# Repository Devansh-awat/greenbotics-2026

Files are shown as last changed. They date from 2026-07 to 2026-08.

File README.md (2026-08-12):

|  |
| :----------------------------------------------------------: |

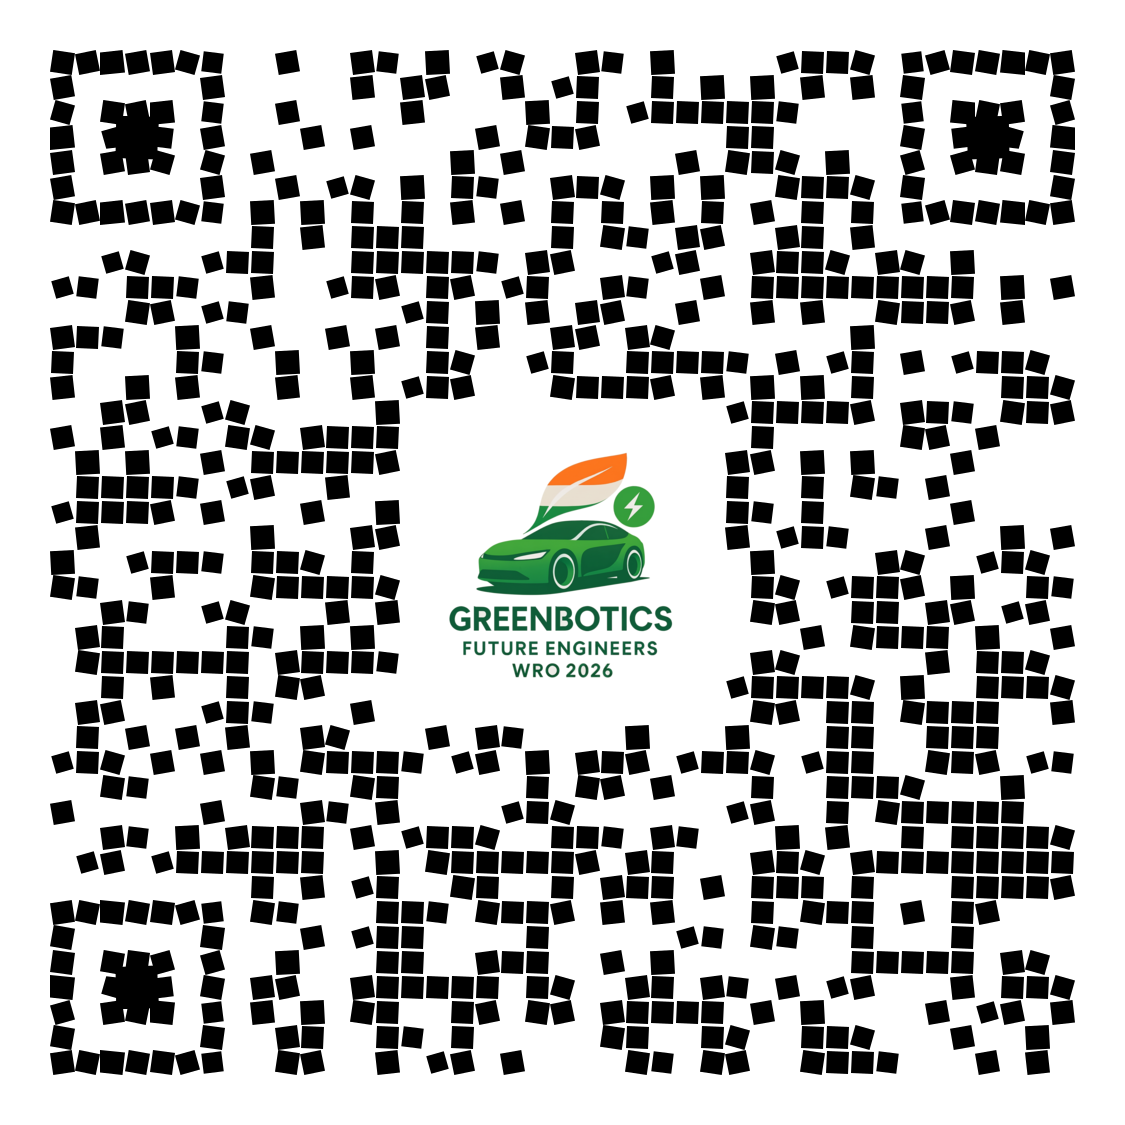
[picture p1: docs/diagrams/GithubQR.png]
GithubQR
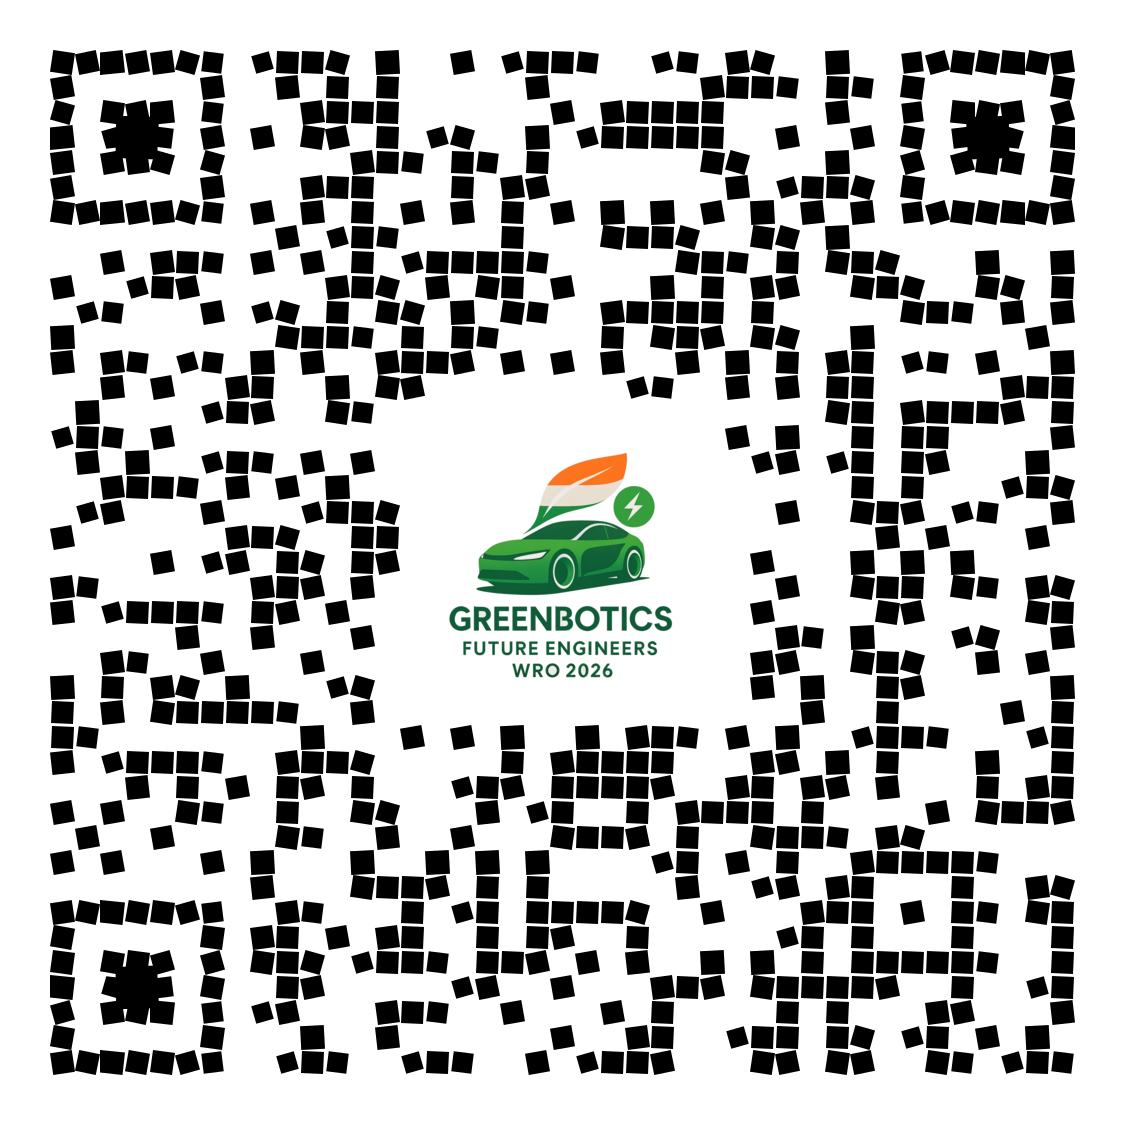
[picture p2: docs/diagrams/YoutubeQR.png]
YoutubeQR
|  |  |
| :--- | ---: |
| Scan QR to open Github repo | Scan QR to open YouTube video |

# Table of Contents

1. [Introduction](#1-introduction)
   - 1.1 [Summary and Performance Video](#11-summary-and-performance-video)
   - 1.2 [Vision](#12-vision)
   - 1.3 [The Team](#13-the-team)
   - 1.4 [Vehicle photos](#14-vehicle-photos)
2. [Mobility & Mechanical Design](#2-mobility--mechanical-design)
   - 2.1 [Drivetrain selection](#21-drivetrain-selection)
   - 2.2 [Steering selection](#22-steering-selection)
   - 2.3 [Vehicle dimensions](#23-vehicle-dimensions)
   - 2.4 [Differential assembly selection](#24-differential-assembly-selection)
   - 2.5 [Wheel selection](#25-wheel-selection)
   - 2.6 [Speed Torque Calculation (Drive Motor Selection)](#26-speed-torque-calculation-drive-motor-selection)
   - 2.7 [Steering Motor selection](#27-steering-motor-selection)
   - 2.8 [3D printed parts](#28-3d-printed-parts)
   - 2.9 [Experiments](#29-experiments)
3. [Power & Sensor Architecture](#3-power--sensor-architecture)
   - 3.1 [Power Budget](#31-power-budget)
   - 3.2 [Power Strategy](#32-power-strategy)
   - 3.3 [Power Verification](#33-power-verification)
   - 3.4 [Wiring Diagram and PCB](#34-wiring-diagram-and-pcb)
   - 3.5 [Sensors](#35-sensors)
   - 3.6 [Microcontroller — Raspberry Pi 5 as Single Controller](#36-microcontroller--raspberry-pi-5-as-single-controller)
   - 3.7 [Calibration Procedures](#37-calibration-procedures)
   - 3.8 [Failure Point Analysis](#38-failure-point-analysis)
   - 3.9 [Iteration Evidence](#39-iteration-evidence)
4. [Software Architecture & Obstacle Strategy](#4-software-architecture--obstacle-strategy)
   - 4.1 [Design Philosophy](#41-design-philosophy)
   - 4.2 [System Architecture](#42-system-architecture)
   - 4.3 [Open Challenge Flow Chart and Algorithm](#43-open-challenge-flow-chart-and-algorithm)
   - 4.4 [Obstacle Challenge — State Machine & Algorithms](#44-obstacle-challenge--state-machine--algorithms)
   - 4.5 [Edge Cases](#45-edge-cases)
   - 4.6 [Parameter Tuning](#46-parameter-tuning)
   - 4.7 [RPM Control — PI Controller with Feed-Forward](#47-rpm-control--pi-controller-with-feed-forward)
   - 4.8 [Testing Results](#48-testing-results)
   - 4.9 [Performance Optimizations](#49-performance-optimizations)
   - 4.10 [Troubleshooting and Debugging](#410-troubleshooting-and-debugging)
5. [Systems Thinking & Engineering Decisions](#5-systems-thinking--engineering-decisions)
   - 5.1 [System Overview](#51-system-overview)
   - 5.2 [Shared Constraints](#52-shared-constraints)
   - 5.3 [Cross-Subsystem Decision Case Studies](#53-cross-subsystem-decision-case-studies)
   - 5.4 [Risk & Failure Modes](#54-risk--failure-modes)
   - 5.5 [Iteration and Testing Cycle Summary](#55-iteration-and-testing-cycle-summary)
6. [Reproducibility & GitHub Organization](#6-reproducibility--github-organization)
   - 6.1 [Repository Structure & Module Map](#61-repository-structure--module-map)
   - 6.2 [Robot Build Instructions](#62-robot-build-instructions)
   - 6.3 [Software Setup & Running the Robot](#63-software-setup--running-the-robot)
   - 6.4 [Testing Workflow](#64-testing-workflow)   
   - 6.5 [Parts List (Bill of Materials)](#65-parts-list-bill-of-materials)
   - 6.6 [Engineering Journal](#66-engineering-journal)
   - 6.7 [Matlab Journal](#67-matlab-journal)

---

# 1 Introduction 
We are team Greenbotics and are competing in WRO 2026 Future Engineers category. This is our second year after a successful participation in WRO 2025, where we were one of the 5 teams to hit a full score(https://scoring.wro-association.org/en/event/scoring/293) in all 4 rounds. You can find our documentation from 2025 here (https://github.com/Devansh-awat/greenbotics).



## 1.1 Summary and Performance Video
Here is a quick 5 min video that summarizes the essence of our robot and documentation. We recommend you watch it to get a quick understanding of our project!

| [Robot Video](https://m.youtube.com/playlist?list=PLMdippUF4xxo) | [YoutubeQR](https://m.youtube.com/playlist?list=PLMdippUF4xxo) <br />Scan QR code to open in YouTube |
| --- | --- |

* [Summary Video](https://youtu.be/YS-oyNQQUGs) 
* [Open Challenge Performance Video](https://youtu.be/OW5V_LRIKNU)
* [Obstacle Challenge Performance Video](https://youtu.be/RbtGV2t9GcI)

## 1.2 Vision
Even though we had a robot from WRO 2025 that performed perfectly across all rounds, we decided to make the most of the 6 months we had to prepare for WRO 2026 by redesigning our robot in every aspect and building it from scratch. This experience gave us tremendous learning.

## 1.3 The Team

<table style="width: 100%; text-align: center; border-collapse: collapse;">
   <tr>
    <td style="padding: 10px;">
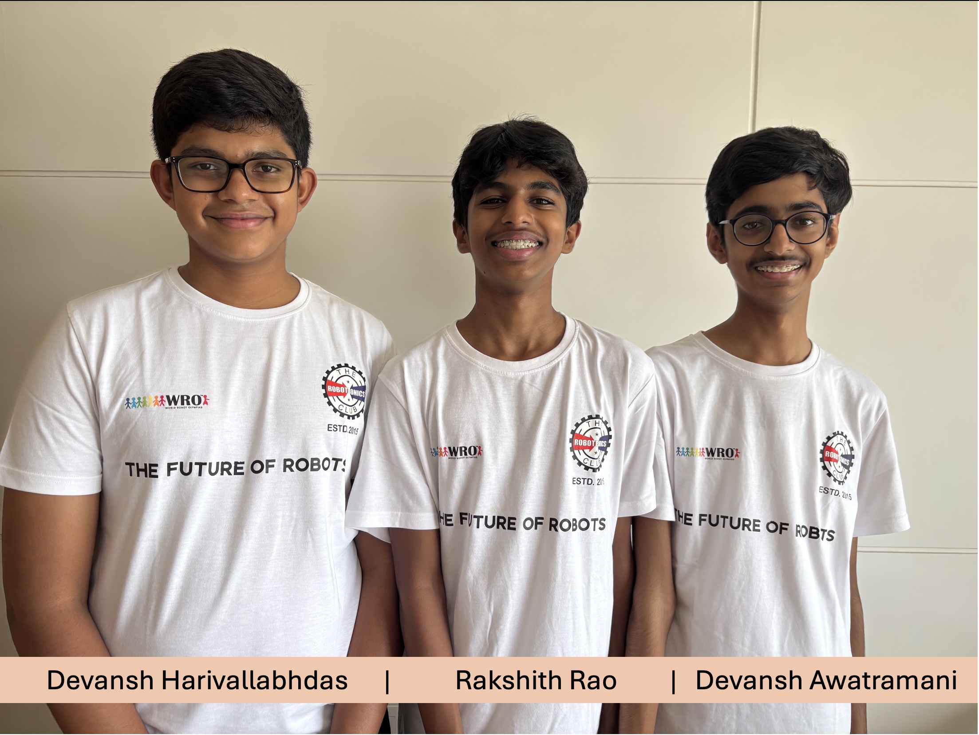
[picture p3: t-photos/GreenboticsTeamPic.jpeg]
      
    </td>
    <td style="padding: 10px;">
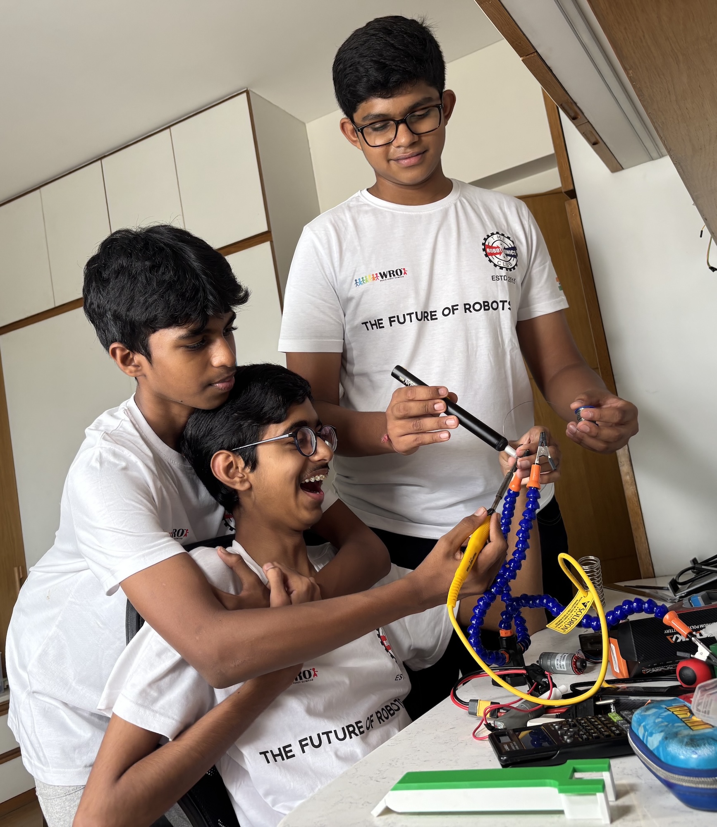
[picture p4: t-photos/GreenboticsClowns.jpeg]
     
    </td>
  </tr>
</table>

Devansh Awatramani and Rakshith Rao are Grade 10 students at The Riverside School, Ahmedabad. Devansh Harivallabhdas is a Grade 11 student at Ahmedabad International School, Ahmedabad.

Paresh Gambhava is our coach from The Robotronics Club, Ahmedabad

## 1.4 Vehicle photos

<table>
  <tr>
    <td align="center">
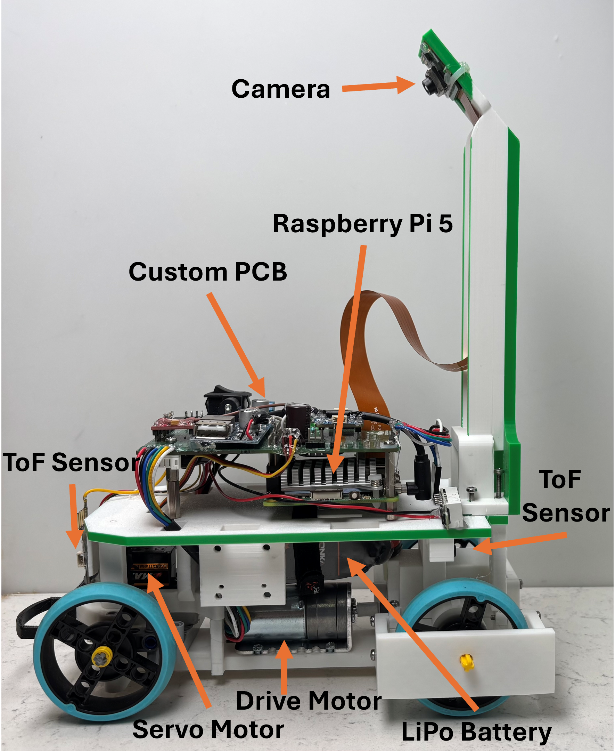
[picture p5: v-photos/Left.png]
Left View
      <br>
      <b>Left</b>
    </td>
       <td align="center">
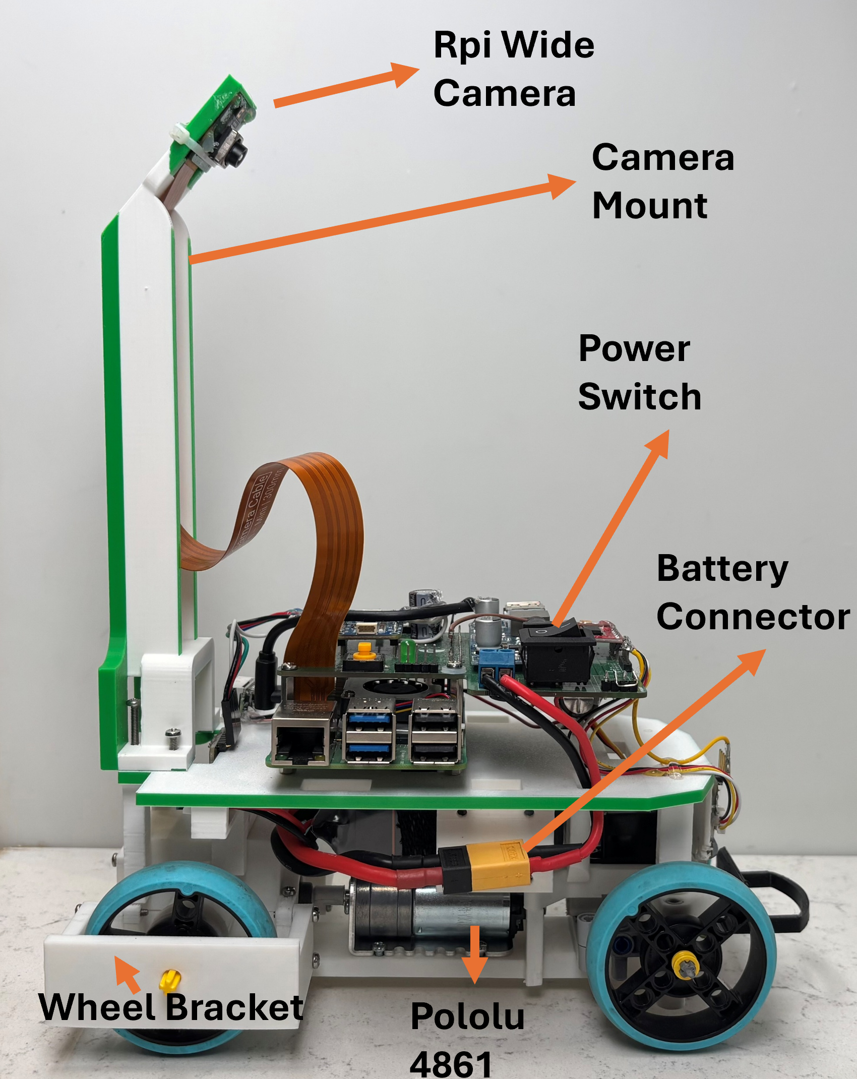
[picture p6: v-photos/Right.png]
Right View
      <br>
      <b>Right</b>
    </td> 
    <td align="center">
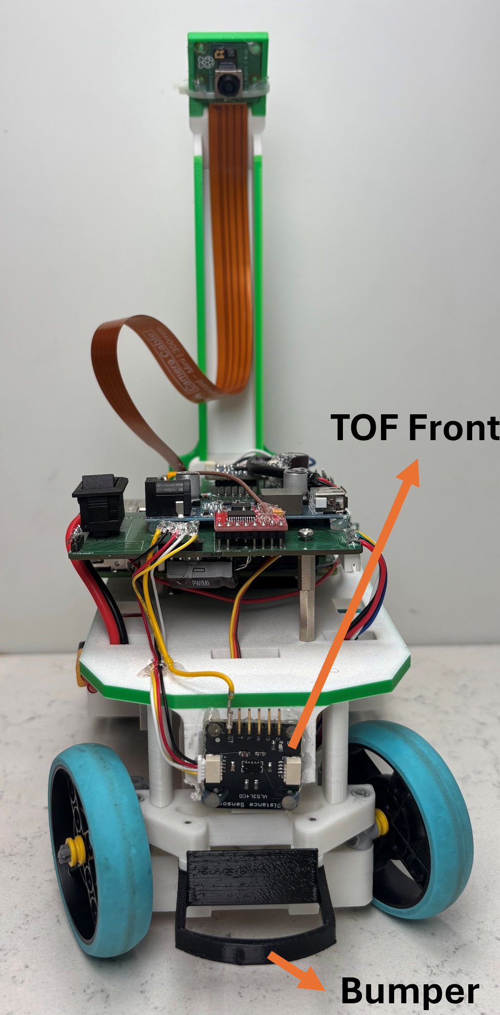
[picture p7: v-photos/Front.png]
Front View
      <br>
      <b>Front</b>
    </td>
    <td align="center">
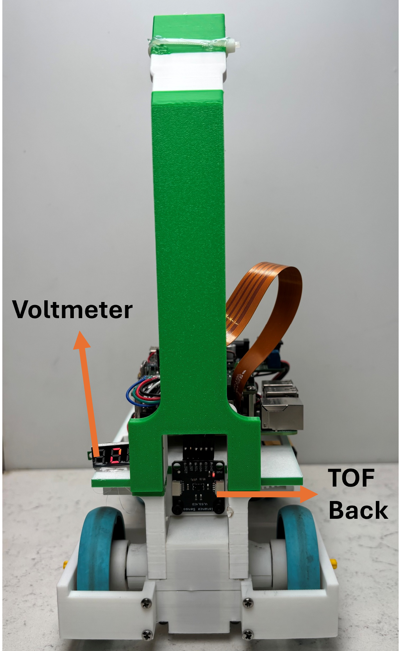
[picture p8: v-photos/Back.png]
Back View
      <br>
      <b>Back</b>
    </td>
   </tr>
</table>

<table>
  <tr>
   <td align="center">
      Top View<br>
      <b>Top</b>
    </td>
    <td align="center">
      Bottom View<br>
      <b>Bottom</b>
    </td> 
  </tr>
</table>

# 2 Mobility & Mechanical Design

This section describes the Mecahnical design of the robot including its chassis, drivetrain and gearbox. It also mentions our experiments, speed & torque calculations, component selection criteria , 3-D designed parts and vehicle photos.

---

## 2.1 Drivetrain selection

WRO rules do not allow a differential drive robot. This steers us towards a real vehicle like design that consists of a front wheel steering. These vehicles have multiple drive options

|  | All Wheel Drive | Front Wheel Drive | Rear Wheel Drive |
| :---- | :---- | :---- | :---- |
|  Driving power | All wheels | Front wheels | Rear wheels |
| Physical complexity | Transfer rotational force to a wheel that is changing its angles with respect to chassis | Transfer rotational force to a wheel that is changing its angles with respect to chassis | Simpler design. Rear axis \- rotational force. Front axis \- turning force |
| Mechanical complexity | Drive motor mounted on steering mechanism. Requires powerful servo due to extra weight | Drive motor mounted on steering mechanism. Requires powerful servo due to extra weight | **Separates mechanical responsibilities.** Steering and Drive motors mounted on separate axis |
| Highlights | Off roading, steep inclines, muddy road | Pulling over obstacles  | Smooth roads, better turns |

We chose RWD for its simpler design and smoother turns.   

<table>
  <thead>
    <tr>
      <th>Differential Gear</th>
      <th>Diagram</th>
    </tr>
  </thead>
  <tbody>
    <tr>
      <td>The rear wheels have a differential gear to prevent inner wheels from skidding when turning. As shown in the diagram, during turns, the outer wheel covers more distance(wo) than inner wheels (wi). In absence of differential gear, the inner wheels would skid.
      </td>
      <td >
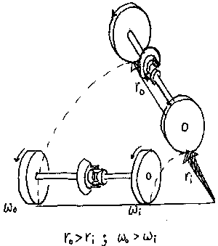
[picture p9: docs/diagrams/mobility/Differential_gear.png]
Differential Gear
       
      </td>
    </tr>
  </tbody>
 </table>   

---

## 2.2 Steering selection

**Ackermann vs Parallel**  
We used Parallel steering in our last year's robot. We realised certain manoeuvres such as entering parking space and tight turns between two inner blocks and inner walls caused tyre slip. We improved upon this aspect for this year's robot by using Ackermann steering. In Ackerman steering, the inner wheel turns slightly more than the outer wheel, so the robot stays on the same arc without tyre slip. This improves maneuverability especially during cornering.

| Ackermann Steering Concept |Our Robot Design | Our Steering Geometry for Ackermann Steering |
| :---: | :---: | :---: |
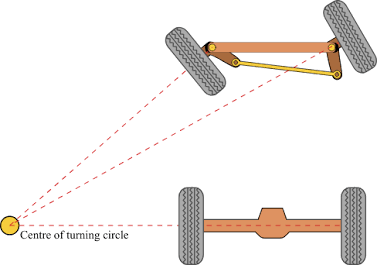
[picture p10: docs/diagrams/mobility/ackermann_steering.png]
Ackermann Steering
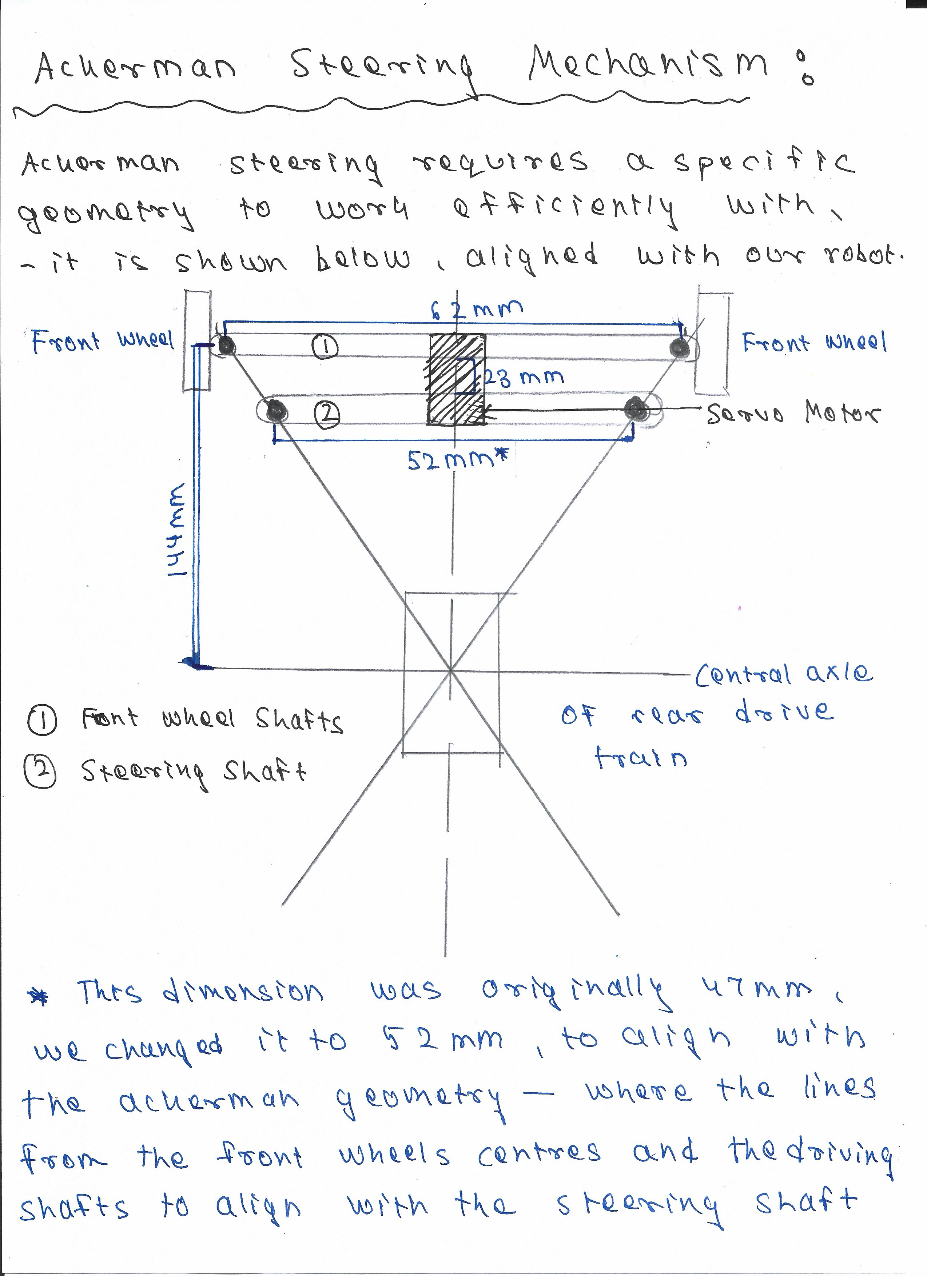
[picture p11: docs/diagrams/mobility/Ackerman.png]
Ackermann Reference Robot Geometry
|  | Ackermann Reference Robot |  |

---

## 2.3 Vehicle dimensions

The defining constraint in this vehicle is its turning radius for its parallel parking. The turning radius is defined by the dimensions of the vehicle.

<table>
  <thead>
    <tr>
      <th>Length Impact & Formula</th>
      <th>Length Visual</th>
      <th>Width Impact & Formula</th>
      <th>Width Visual</th>
    </tr>
  </thead>
  <tbody>
    <tr>
      <td>
        <strong>Length Impact</strong><br>
        <em>R = L / sin(θ)</em><br>
        Turning Radius(R) scales proportionally with the Length(L) of the vehicle.
      </td>
      <td>
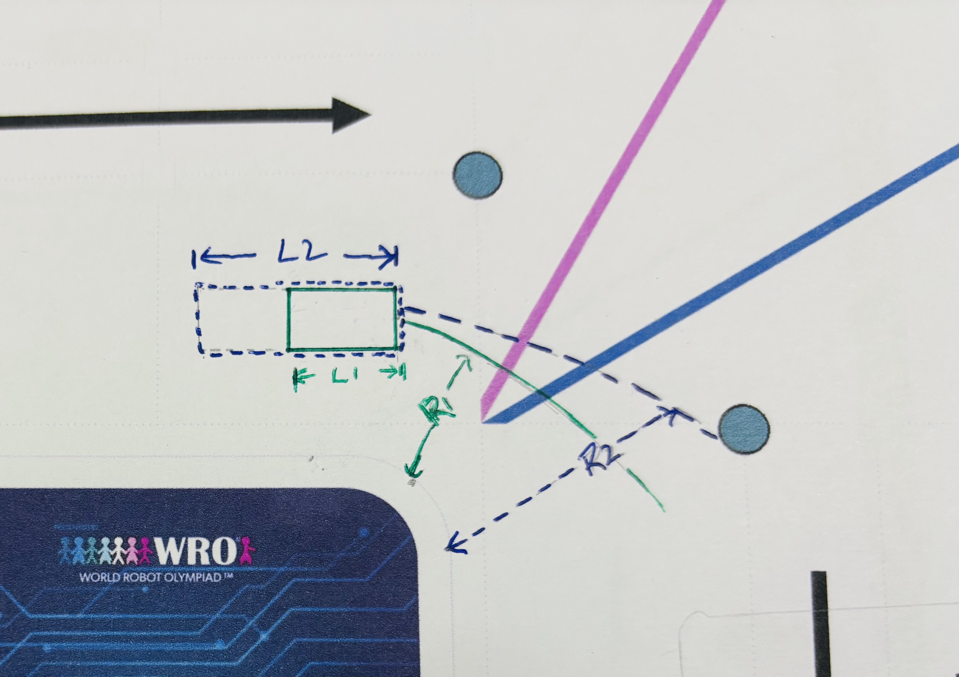
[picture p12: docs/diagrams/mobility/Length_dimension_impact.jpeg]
Vehicle Length Impact Diagram
        
      </td>
      <td>
        <strong>Width Impact</strong><br>
        <em>R(outer) = R(center) + W/2</em><br>
        Width does not change the turning radius, but increases the outer clearance radius.
      </td>
      <td>
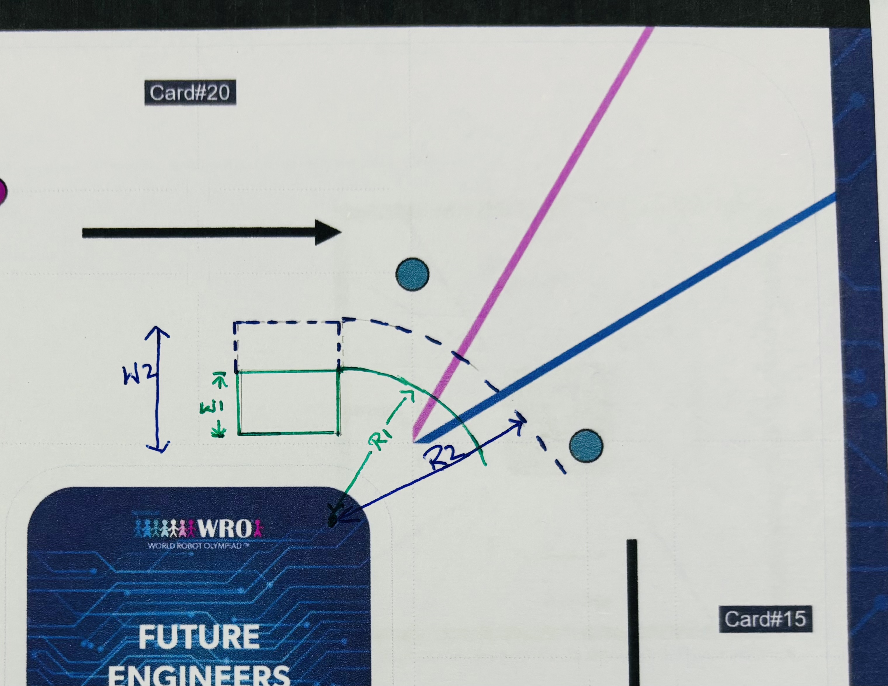
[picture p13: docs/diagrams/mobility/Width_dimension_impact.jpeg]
Vehicle Width Clearance Diagram
        
      </td>
    </tr>
  </tbody>
</table>

We strive to keep both the Length and Width as minimum as possible.  
Length is the minimum length to accommodate the differential gear assembly, drive motor and the steering assembly back to back.  
Width is the minimum width for the differential assembly, couplings and the wheels attached back to back.  
This results into a 23 cm long and 12 cm wide vehicle.

---

## 2.4 Differential assembly selection

We used Lego differential gear assembly in our last year's robot. While this gave us adequate performance, there were few drawbacks to it

1) Gear damage: Plastic gears chip away after continued use..  
2) Backlash: When the robot makes micro adjustments during parking switching from forward to reverse, the motor rotates slightly before the wheels actually move. This makes software control of the robot inconsistent. If we move the motor a bit more, the robot sometimes hits the walls, if we make the motor move a bit less, it doesn't move.

Both these problems can be resolved with metal differential gears. To allow for precise control, we chose the largest possible gear ratio that could fit in the chassis. We chose a metal differential gear with a 38:13 ratio of ring gear to pinion gear. This gear ratio gives higher torque providing reliable transmission even at lower speeds. There is loss of top speed, but we do not need to race the car so that is fine.

| Feature | Plastic Differential (e.g., LEGO) | Metal Differential |
| :---- | :---- | :---- |
| **Backlash**  | High (Rough control at low speed during parking) | Low (Precise control at low speed during parking) |
| **Friction** | Plastic-plastic \- higher friction (Prone to low-speed jerky motion) | Metal-metal \- lower friction (Smooth low-speed crawl) |
| **Rigidity / Prone to damage** | Teeth Chip away after continued usage | Rigid and stable |
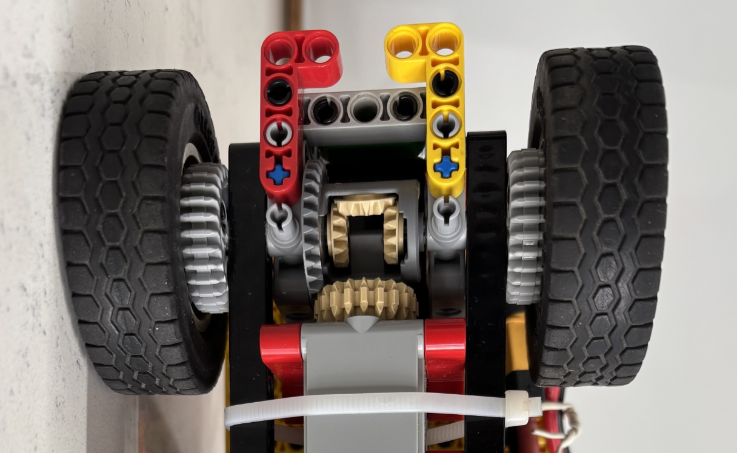
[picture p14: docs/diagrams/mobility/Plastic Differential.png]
Metal Plastic Differential gear
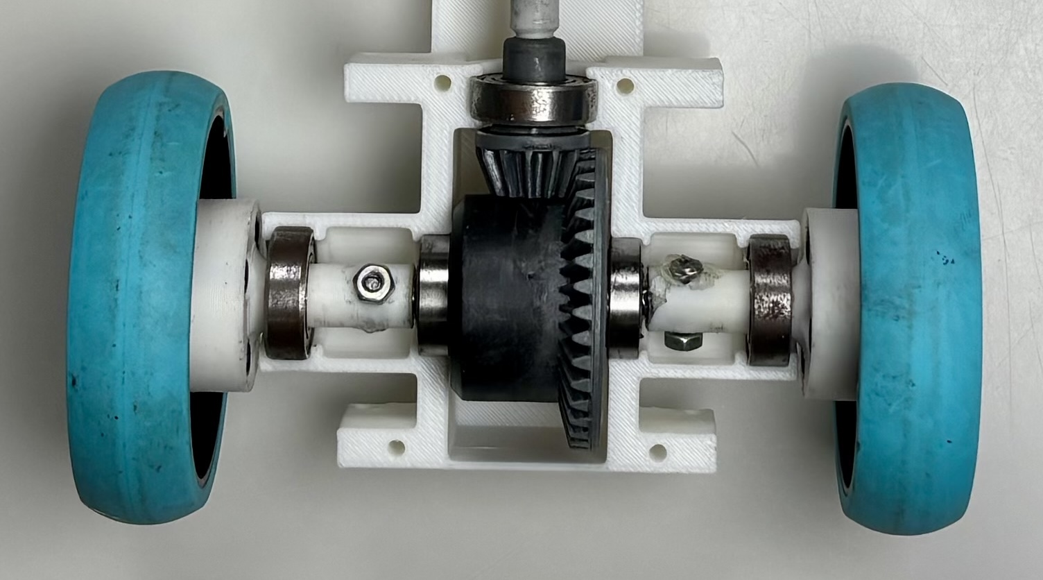
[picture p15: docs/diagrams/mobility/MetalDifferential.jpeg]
Metal Plastic Differential gear
| **Robot Image with Gear** |||

---

## 2.5 Wheel selection

We used lego spike prime medium wheels with 56mm diameter and 14 mm wide. These are narrow bicycle like wheels giving smoother turns. A bigger wheel would amplify the backlash causing imprecise movements during parking.

We also tried 3D printing our own custom wheels, and coating it with a cricket bat's rubber grip. But we realised we couldn't match the fit and finish of a pre-fabricated Lego wheel.

[For Wheel Attempts refer Section 5.5.1 3D Iterations](#551-3d-chassis-iterations)

---

## 2.6 Speed Torque Calculation (Drive Motor Selection) 

We used a Lego EV3 medium motor in our last year's robot and its speed was the limiting factor for our robot. We were running the motor at 100% speed and couldn't go faster.   
Old robot rpm at wheel

```
rpm_wheel_old = rpm_motor_old / differential_gear_ratio_old

rpm_wheel_old = 250 / (28 / 20) = 250 / 1.4 = 179
```

We wanted the new robot to go at least 50% faster with enough headroom so we aimed for 100% higher rpm at wheel

```
rpm_wheel_new = rpm_motor_new / differential_gear_ratio_new

rpm_wheel_new = 2 * rpm_wheel_old = 2 * 179 = 358

358 = rpm_motor_new / (38 / 13)
rpm_motor_new = 358 * (38 / 13) = 358 * 2.92 = 1045
```

We explored different motors from [Pololu](https://www.pololu.com/product/4861) as they offer a wide range of gear ratios. We ran below Speed Torque calculations with some motors and shortlisted Pololu 4861 that provides 0.71 kg·cm torque @ 1800 rpm. This motor runs at 12V removing the need for a step down converter and associated efficiency losses.

| Criteria | LEGO EV3 Medium Motor | Pololu 4861 |
| :---- | :---- | :---- |
| Power supply match | Needs buck converter (12 V → 9V), small conversion loss | Runs directly off 12 V LiPo, no converter required |
| Mechanical reliability | Plastic gears —  can slip or chip away and has higher backlash | All-metal gearbox — More reliable and has lower backlash |
| No load speed | 250 rpm | 1800 rpm |
| Stall torque | 1.22 kg·cm | 0.71 kg·cm |
| Rated stall current | 0.8 A | 1.8 A |

The Pololu motor natively matches the power source and has better mechanical reliability.

### 2.6.1 Speed Torque calculations

| Symbol | Meaning | Value |
| :---- | :---- | :---- |
| m | Robot mass | 0.8 kg |
| g | Gravitational acceleration | 9.81 m/s² |
| W | Robot weight \= m × g | 7.85 N |
| D\_w , r\_w | Wheel diameter / radius | 0.056 m / 0.028 m |
| N\_nl | Motor no-load speed at gearbox output (12 V) | 1800 RPM |
| T\_stall\_gb | Stall torque at gearbox output (extrapolated) | 0.71 kg·cm \= 0.0696 N·m |
| I\_stall | Stall current | 1.8 A |
| G\_ext | External gear ratio (13:38 metal differential) | 38 / 13 \= 2.923 |
| μ | Wheel-to-mat friction coefficient (assumed) | 0.6 (rubber-type wheel on flex banner) |
| C\_rr | Rolling resistance coefficient (assumed) | 0.03 |
| C\_rr,static | Higher than C\_rr due to stiction | 0.05 |
| T\_cont\_gb | Recommended continuous torque at gearbox output | 25% of T\_stall\_gb (manufacturer guideline: keep current ≤ 25% of stall) |

**No load speed**

```
v_nl = (π × D_w × N_nl) / (60 × G_ext)

v_nl = (π × 0.056 × 1800) / (60 × 2.923) = 1.81 m/s
```

**A) Starting Torque v/s Stall Torque rating**

Can the motor move the robot from a dead stop? The motor is in stall condition at the moment it starts and the stall torque should exceed the initial resistance(static friction) that the robot needs to begin moving.

**B) Running Torque v/s Continuous Torque rating**

Is the torque required for continuous driving comfortably within motor's output to avoid constantly overloading the motor that could result in motor breakdown

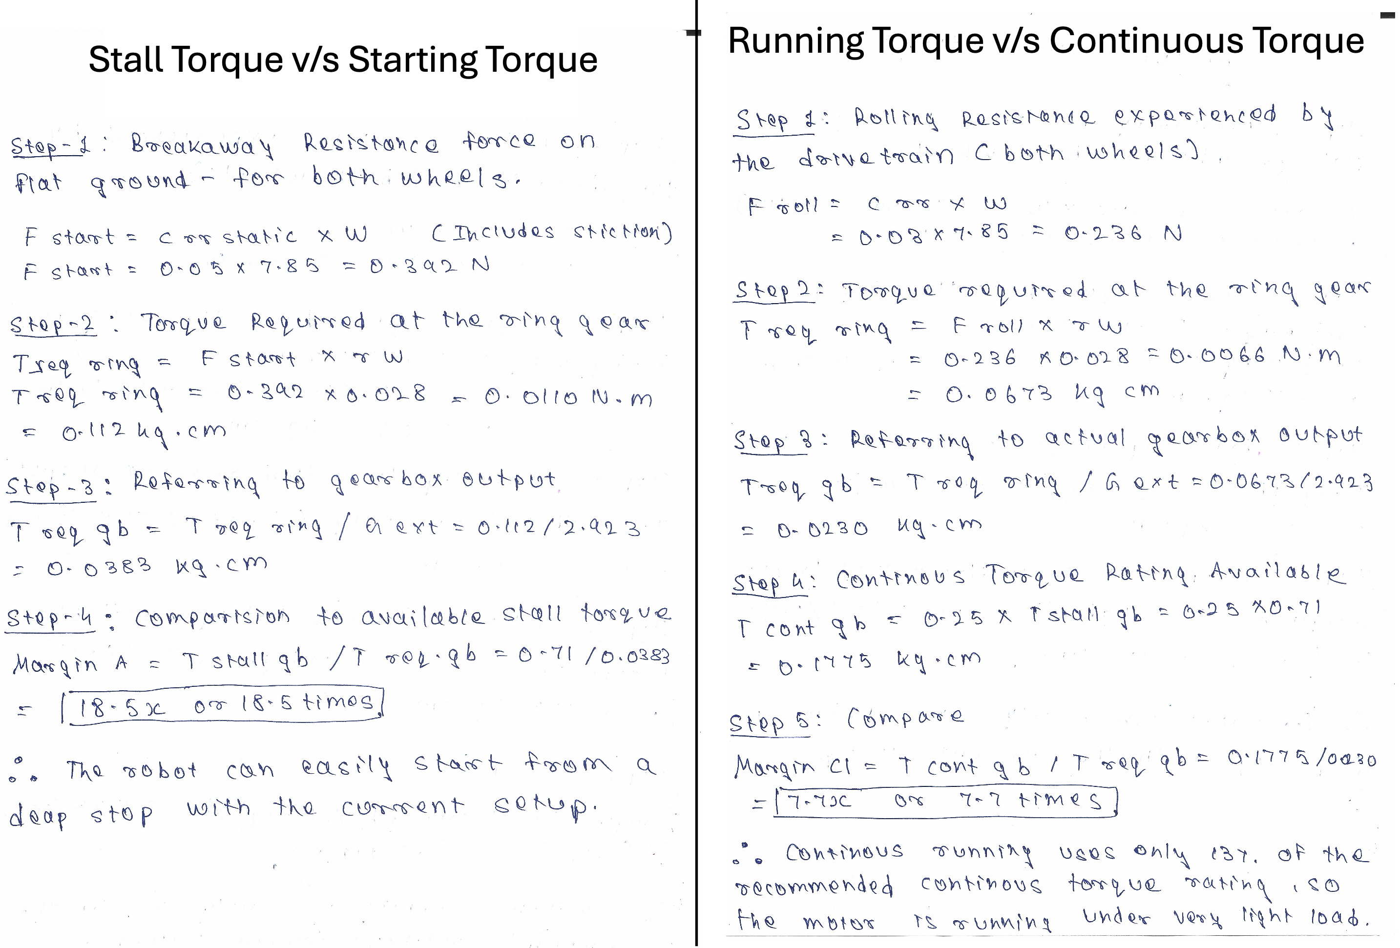
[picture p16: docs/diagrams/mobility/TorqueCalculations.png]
Starting Torque Calculation


**C) Running speed v/s No load speed**

The Pololu 4861 datasheet ([https://www.pololu.com/file/0J1829/pololu-25d-metal-gearmotors-rev-2-0.pdf](https://www.pololu.com/file/0J1829/pololu-25d-metal-gearmotors-rev-2-0.pdf)) shows that torque and speed are linearly related. 

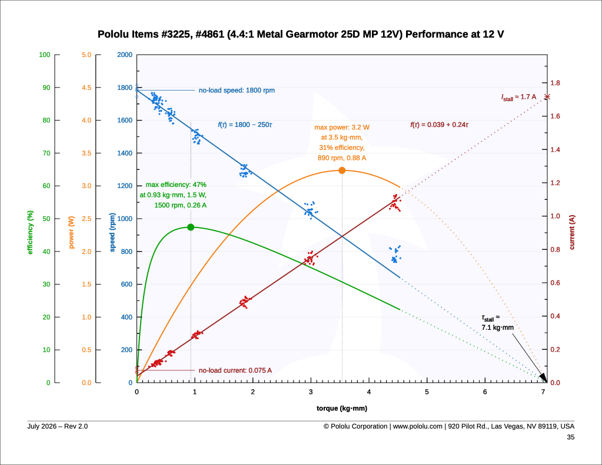
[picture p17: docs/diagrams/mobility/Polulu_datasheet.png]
Pololu Datasheet


Using the fraction of stall torque with the running torque from (b) 

```
N_gb = N_nl × (1 − T_req,gb / T_stall_gb)

N_gb = 1800 × (1 − 0.0230/0.71) = 1800 × 0.9676 = 1741.7 RPM

N_wheel = N_gb / G_ext = 1741.7 / 2.923 = 595.8 RPM

v = π × D_w × N_wheel / 60 = π × 0.056 × 595.8 / 60 = 1.75 m/s
```

*Conclusion:* The running speed (1.75 m/s) should be very close to the no load speed (1.81 m/s).

**Experiment Metrics**
|Theortical No Load Speed| Theoritical Running Speed |Observed Running Speed|
|---|---|--|
|1.81 m/s|1.75 m/s|1.54 m/s|

**Assumptions**

Our calculations assumed no loss at differential gear. However a differential gear would have efficiency of **η=85%** due to frictional losses. But, its impact wouldn't be of concern to us as we have a very high margin.

**Summary**

| Check | Question answered | Torque req'd at gearbox (kg·cm) | Torque available (kg·cm) | Margin |
| :---- | :---- | :---- | :---- | :---- |
| A: Starting Torque v/s Stall Torque rating | Can it start moving from rest? | 0.0383 | 0.71 (stall) | 18.5× |
| B: Running Torque v/s Continuous Torque rating | Can it sustain cruising without overheating? | 0.0230 | 0.1775 (25% cont.) | 7.7× |

The Pololu motor has adequate torque margin to start the robot from rest, sustain cruising without overheating and to provide the max speed we could possibly use.

---

## 2.7 Steering Motor selection

For our last year's robot, we used an SG90 servo motor for front wheel steering for precise steering control. While it was adequate, we explored other alternatives.

| SG90 | EMAX ES08A II |
| :---- | :---- |
| Softer Plastic gears prone to wear and stripping | Higher Grade Plastic and Robust Motor |
| deadband drift \- steering drifts over time | tighter deadband \- precise steering positioning |
| speed \- 0.10 sec/60° | speed \- 0.10 sec/60° |
| torque \- 1.6 kgf·cm | torque \- 2.0 kgf·cm |

We did have one instance of SG90 breaking last year so we chose the EMAX servo motor primarily for higher durability and secondarily for similar or better steering precision.

---

## 2.8 3D printed parts
Our robot structure is entirely 3-D designed. Here is how the various 3-D parts connect together to give structure to our robot. 
[Click Here to see how we iterated to reach these final parts](#551-3d-chassis-iterations)

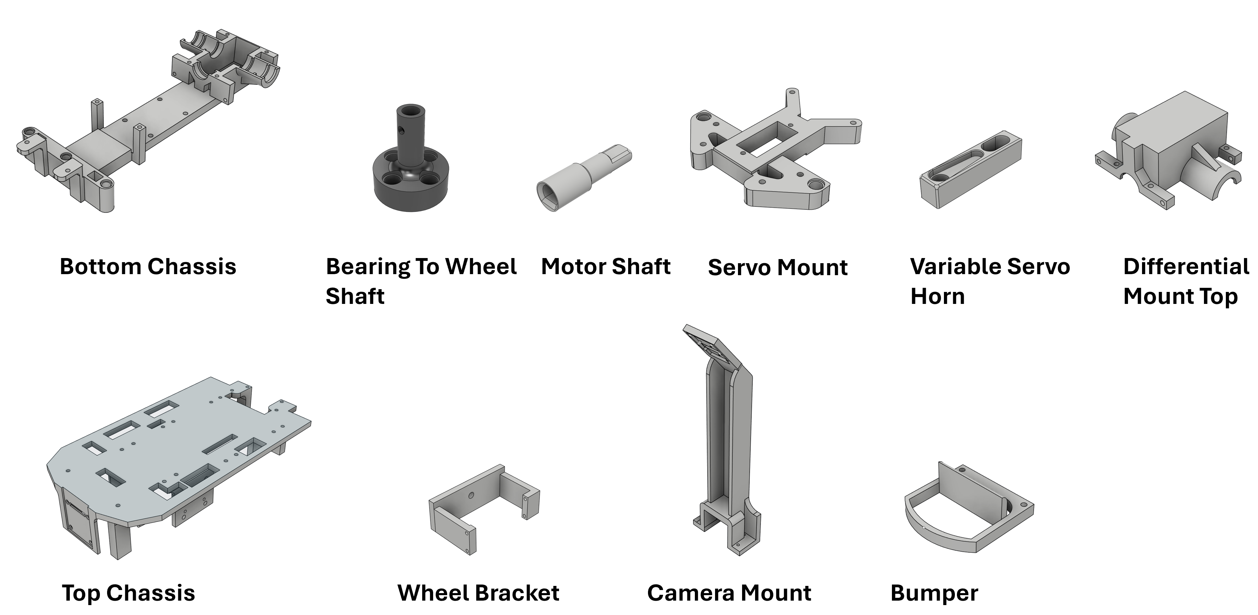
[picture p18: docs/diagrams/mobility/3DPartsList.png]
3 D parts
  

**[Link for all 3-D modelled parts photos ](schemes/)**

**[Link for all 3-D parts  STL files](models/chassis/)**

---

## 2.9 Experiments

We ran some experiments to determine our robot precision. This data helps us calibrate robot speed for various scenarios like open challenge, obstacle challenge and parking section.

### 2.9.1 Detection distance v/s speed

We ran the robot in a straight line until it found an obstacle 20 cm in front of it. The robot started breaking at the point the sensor triggered. This measures the time taken by the robot to come to a complete halt. This helps us determine how slowly the robot should move at critical points e.g. parking section.

<table>
  <tr>
    <!-- Left Column: Data Table -->
    <td valign="top">
      <table border="1" cellpadding="5" cellspacing="0">
        <thead>
          <tr>
            <th>Speed (m/s)</th>
            <th>Stopping Time (ms)</th>
            <th>Stopping Distance (cm)</th>
          </tr>
        </thead>
        <tbody>
          <tr><td align="center">0.199</td><td align="center">111</td><td align="center">0.51</td></tr>
          <tr><td align="center">0.265</td><td align="center">237.5</td><td align="center">1.65</td></tr>
          <tr><td align="center">0.334</td><td align="center">266.6</td><td align="center">2.57</td></tr>
          <tr><td align="center">0.396</td><td align="center">256.2</td><td align="center">2.76</td></tr>
          <tr><td align="center">0.456</td><td align="center">301</td><td align="center">3.59</td></tr>
          <tr><td align="center">0.523</td><td align="center">335</td><td align="center">4.6</td></tr>
          <tr><td align="center">0.588</td><td align="center">370</td><td align="center">5.8</td></tr>
          <tr><td align="center">0.653</td><td align="center">410</td><td align="center">7.1</td></tr>
          <tr><td align="center">0.719</td><td align="center">450</td><td align="center">8.6</td></tr>
          <tr><td align="center">0.784</td><td align="center">490</td><td align="center">10.2</td></tr>
        </tbody>
      </table>
    </td>
    <!-- Right Column: Chart Image -->
    <td valign="top" style="padding-left: 20px;">
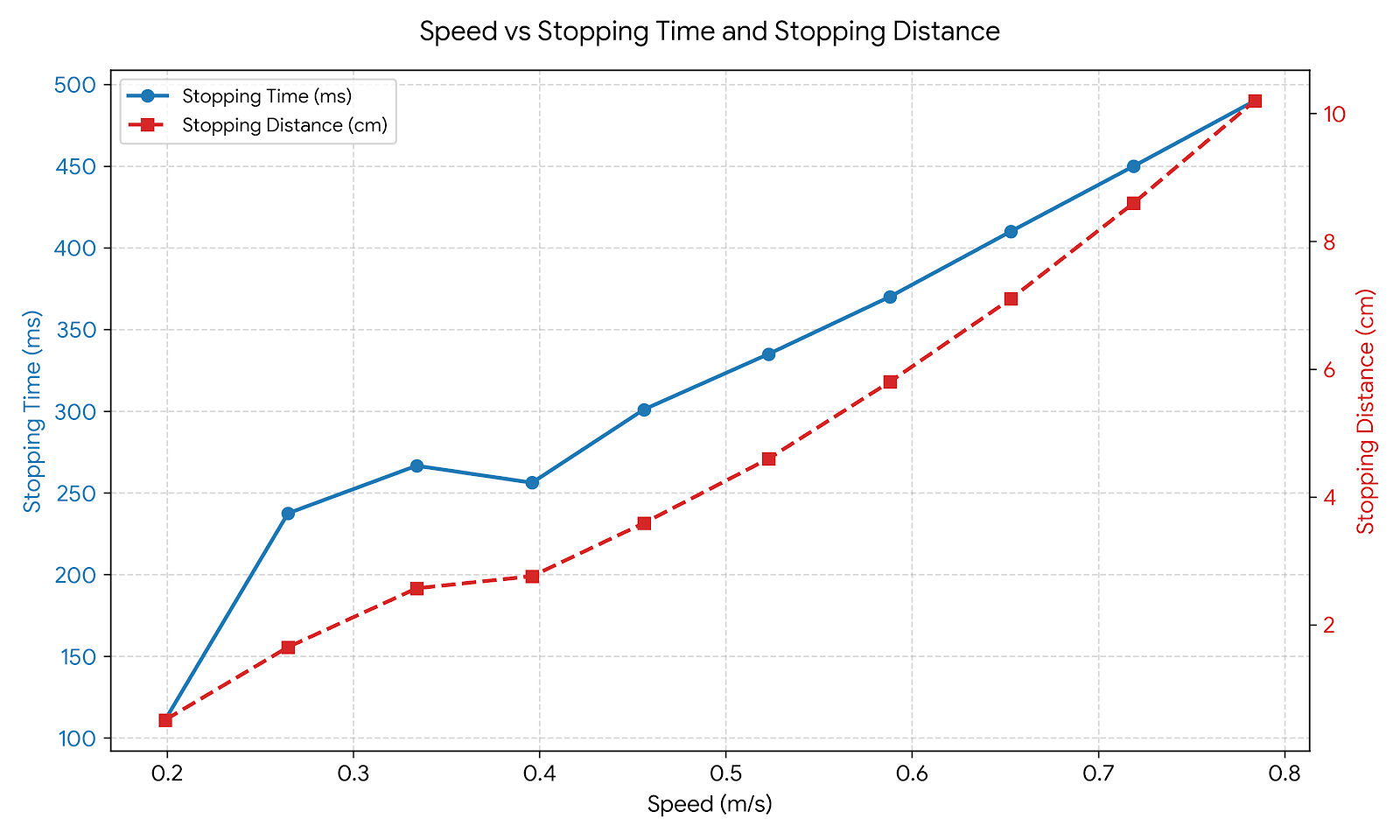
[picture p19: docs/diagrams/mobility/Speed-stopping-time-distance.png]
Speed vs Stopping Time and Distance Chart
      
    </td>
  </tr>
</table>

**Conclusion** This experiment proves that at higher speed the time taken to come to a full stop as well as distance covered before it actually stop increases, so we need to ensure robot is moving at the right speed for it to stop and turn accurately in parking or while avoiding obstacles.

### 2.9.2 Encoder precision and tuning

We used the encoder specifications and gear ratio to tune the encoder. Then we measured the actual distance travelled when it was given a particular instruction to verify its accuracy.

| Run # | Encoder measured distance (cm) | Observed distance practically (cm) | Δ distance (cm) |
| :---: | :---: | :---: | :---: |
| 1 | 100 | 92 | 8 |
| 2 | 50 | 47 | 3 |

**Conclusion** We designed our software to be able to handle the accuracy that the actual encoder can provide. 

---

# 3 Power & Sensor Architecture

A 11.1V 1500mAh 16.65 Wh LiPo battery powers all the electronics on our robot. It drives a 25W power converter providing 5.2V to the Raspberry Pi 5 and the Servo motor, while the battery directly provides 11.1V to the Drive motor. The RPi 5 further powers the camera and sensors via its 3.3V GPIO rail.

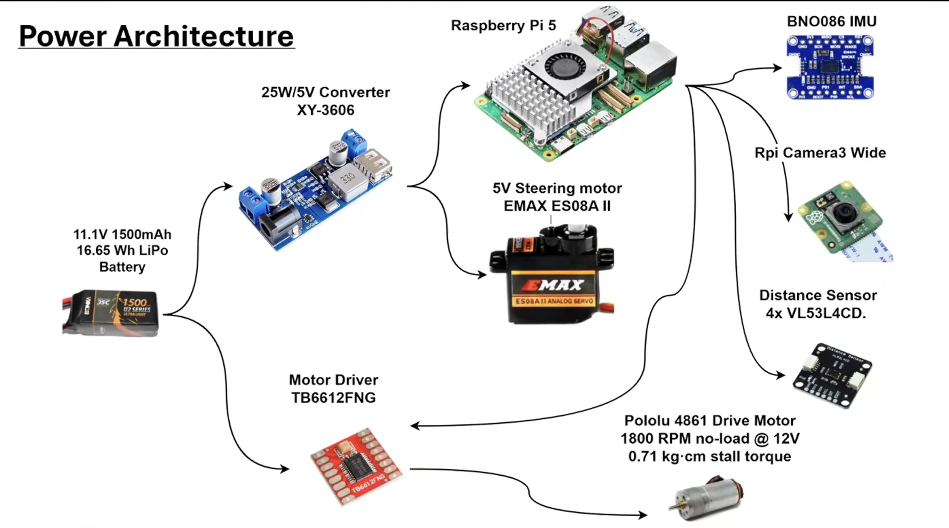
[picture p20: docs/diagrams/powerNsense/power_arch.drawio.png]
Power and Sense Architecture


---

## 3.1 Power Budget

We referred to components documentation to find out their voltage and current specifications.

| Devices on 5V power bus | Volts (V) | Idle Current (A) | Typical Current (A) |
| :---- | :---- | :---- | :---- |
| Raspberry Pi 5 | 5.0 | 0.600 | 0.750 |
| Servo - EMAX ES08A II | 5.0 | 0.010 | 0.200 |
| Camera module 3 wide | 5.0 | 0.250 | 0.280 |
| BNO086 IMU | 3.3 | 0.008 | 0.012 |
| VL53L4CD ToF sensor (x4) | 3.3 | 0.020 | 0.080 |
| Total load on 5V power bus | 5.0 | 0.888 | 1.322 |

| Devices on 11V power bus | Volts (V) | Idle (A) | Typical (A) |
| :---- | :---- | :---- | :---- |
| Motor driver - TB6612 FNG (Logic/VCC) | 5.0 | 0.001 | 0.002 |
| Motor - Pololu 4861 | 11.1 | 0.000 | 0.400 |
| Total load on 11V power bus | 11.1 | 0.001 | 0.402 |

\* Current values sourced from component datasheets and other sources.

Using values from the above table, we did **calculation for the need of current and power for our robot**, considering all circuit components.

| Calculation | Idle Current | Typical Current|
| :---- | :---- | :---- |
| **5V Bus** | | |
| Output power = Voltage × Current | 5V × 0.888A = 4.44W | 5V × 1.322A = 6.61W |
| Input power = Output power / Efficiency (95%) | 4.44W / 0.95 = 4.67W | 6.61W / 0.95 = 6.96W |
| **11V Bus** | | |
| Output power = Voltage × Current | 11.1V × 0.001A = 0.011W | 11.1V × 0.402A = 4.462W |
| Input power = Output power / Efficiency (97.5%) | 0.011W / 0.975 = 0.011W | 4.462W / 0.975 = 4.577W |
| **Battery Total** | | |
| Power drawn = 5V input + 12V input | 4.67 W + 0.011W = **4.68W** | 6.96W + 4.577W = **11.537** |
| Current drawn = Power / Battery voltage (11.1V) | 4.68W / 11.1V = **0.422A** | 11.537W / 11.1V = **1.039A** |

---

## 3.2 Power Strategy

### 3.2.1 Battery Runtime Estimation
 
```
Battery specifications 
Nominal voltage = 11.1V  
Full charge voltage = 12.6V  
Capacity             = 1500mAh  
Discharge rating = 35C  
Max discharge current = capacity * C rating  
                                     = 1.5Ah * 35  
                                     = 52.5A  
Headroom v/s C rating = max discharge current / current drawn from battery  
                                     = 52.5A / 1.039A  
                                     = 50.53 x (burst that the battery can handle)

Total energy stored = capacity * nominal voltage  
                                = 1.5Ah * 11.1V  
                                = 16.65Wh

Estimated runtime = Total energy / Power drawn from battery (typical)  
                              = 16.65Wh / 11.537W  
                              = 1.44 hours
```
Applying a safety margin of 30% to avoid over discharging the battery, we comfortably get a runtime of over an hour for typical power consumption.
Moreover, we have added a **Battery Level Indicator**(Voltmeter) which allows us to be aware of the battery voltage at all times and we can ensure the battery doesn’t discharge deeply during practice and that it’s fully charged before the competition. 

### 3.2.2 Voltage Converter

The 25W/5V converter provides USB compatible output suited for RPi 5's USB power input.  
```
RPi's operational power requirement = 6.96W     	Converter's output power = 25W  
```
This is **more than 3X the required power** to account for spikes.  

---

## 3.3 Power Verification

### 3.3.1 Full Circuit Loop Measurement

A multimeter was put in series in the LiPo battery path and the robot run on a raised platform to measure the typical operating current.

| Condition | Measured current (A) | Theoretical current (A) |
| :---- | :---- | :---- |
| Idle operation | 0.350 to 0.420 (across multiple readings) | 0.422 |
| Typical operation | 0.780 to 0.990 (across multiple readings) | 1.039 |

### 3.3.2 5V Power Bus — Onboard Telemetry

We used pmic_read_adc diagnostic command from Raspberry Pi 5 to read real-time voltage and current measurements from its built-in Power Management IC. The telemetry total power almost matches the theoretically calculated power for RPi and sensors connected to it.

[For Telemetry- See Power Profile Script](src/tools/power_profile.py)

<table>
  <thead>
    <tr>
      <th>Multimeter Measurement</th>
      <th>Telemetry Output</th>
    </tr>
  </thead>
  <tbody>
    <tr>
      <td align="center">
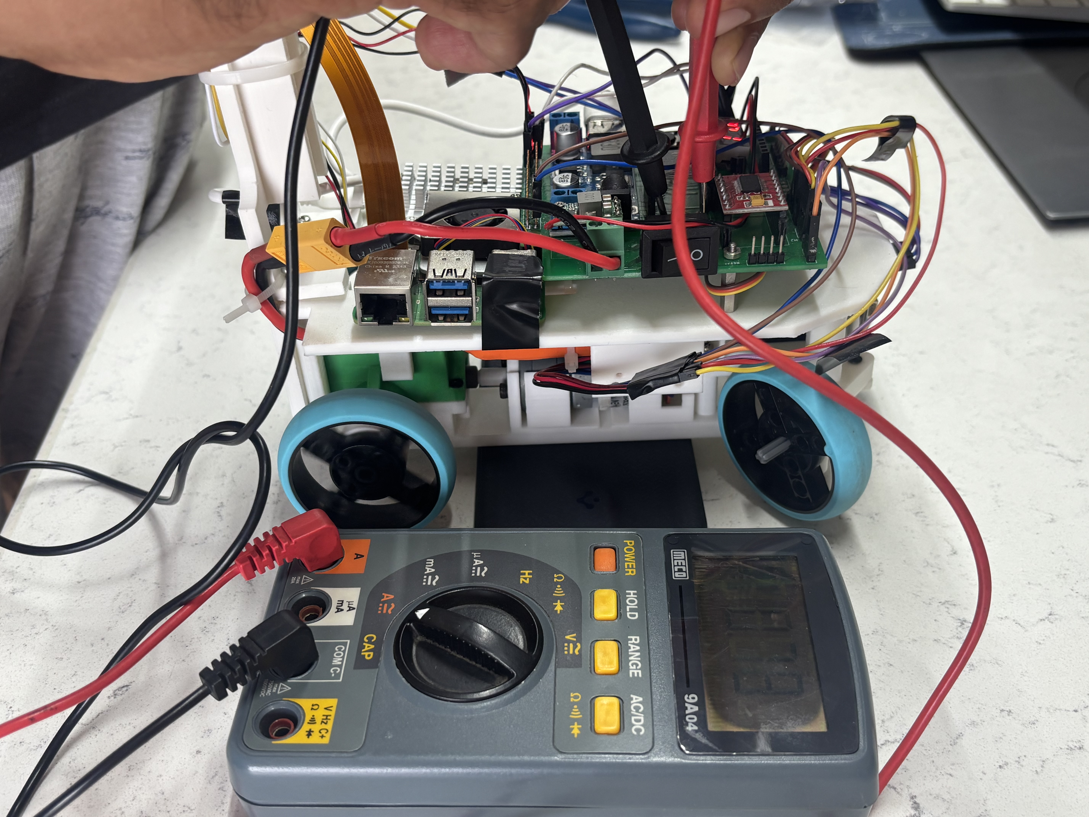
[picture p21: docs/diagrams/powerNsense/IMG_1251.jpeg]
Multimeter Measurement
        
      </td>
      <td align="center">
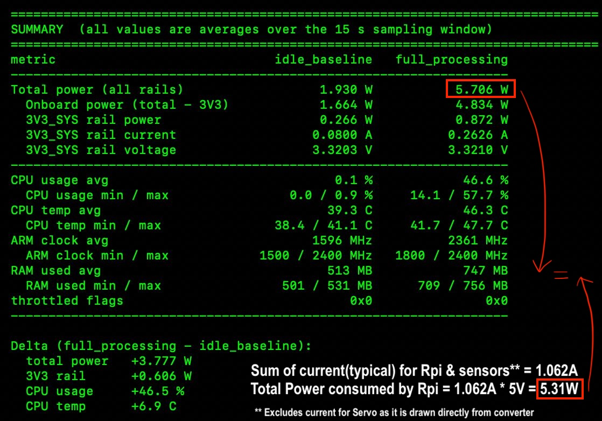
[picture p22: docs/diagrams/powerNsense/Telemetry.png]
RPi 5 PMIC Telemetry Output
        
      </td>
    </tr>
  </tbody>
</table>

---

## 3.4 Wiring Diagram and PCB

In our first draft of the robot, there were many criss-crossing wires between many different components. A lack of clean arrangement for the wires made the robot very messy to handle. During practice runs, wires would routinely get loose, making it difficult to troubleshoot errors.

To solve this, we designed a PCB which cleanly connected all of our components together, making the robot far cleaner and reliable.
Here's  simplified pin layout diagram for the wiring.

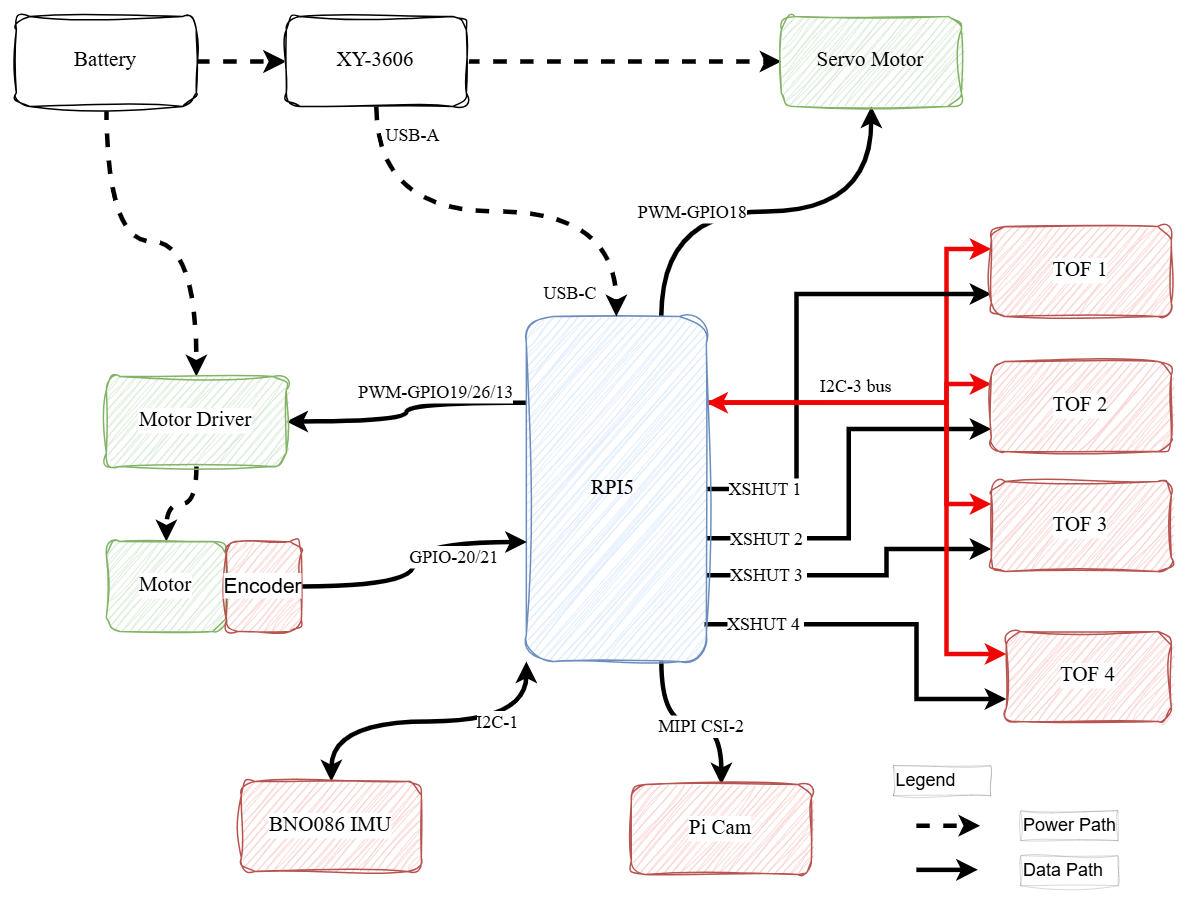
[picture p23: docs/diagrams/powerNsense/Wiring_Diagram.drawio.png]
Wiring Diagram


The complete Circuit diagram below shows all power and signal connections between the battery, voltage converters, Raspberry Pi 5, motor driver, servo, camera, IMU, and ToF sensors.

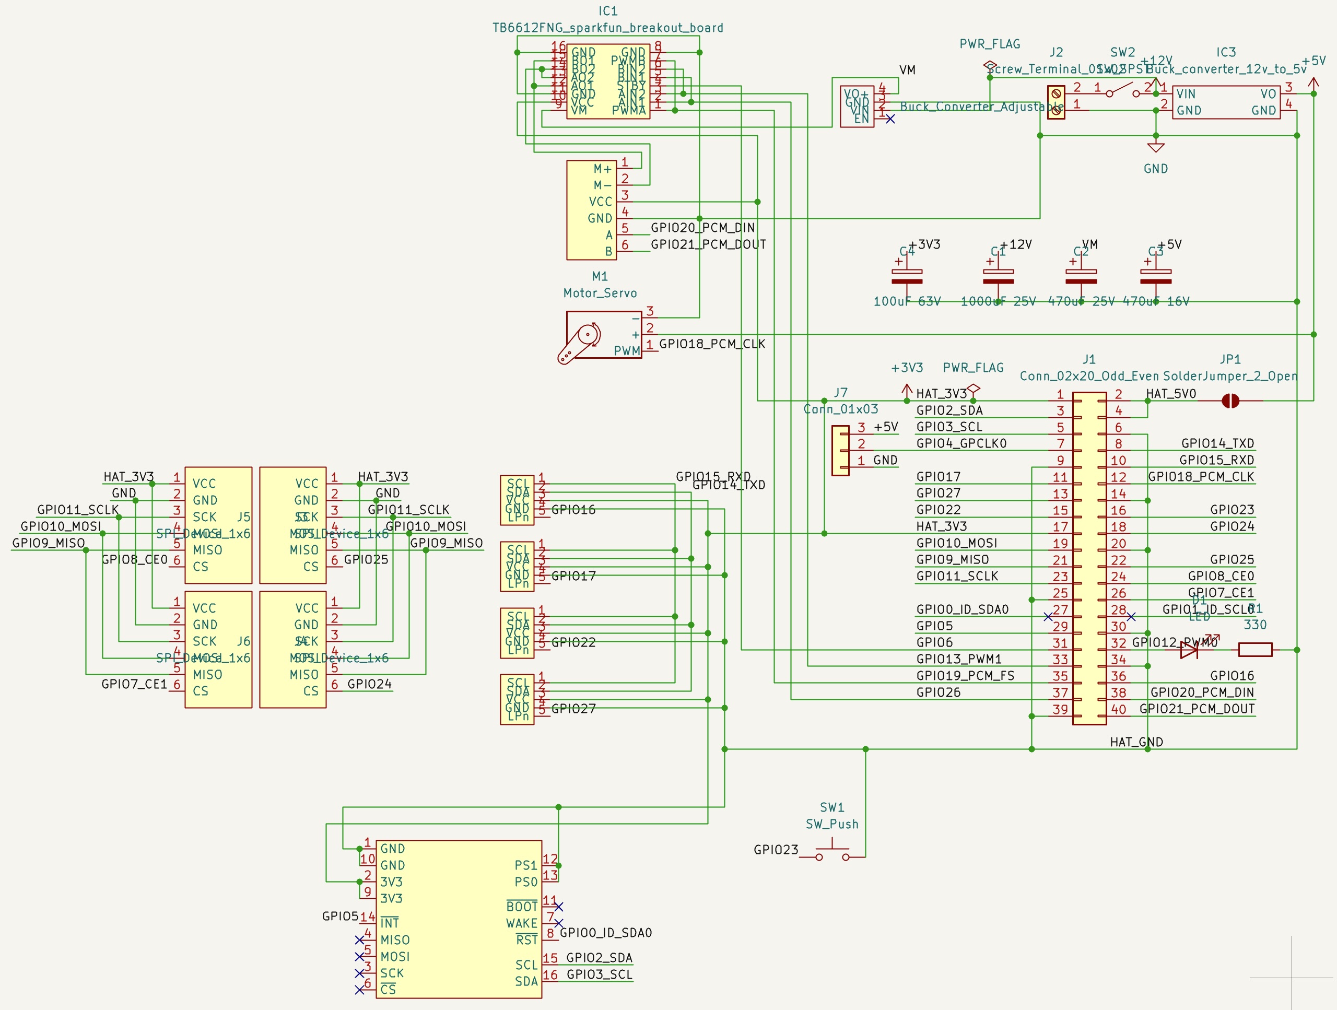
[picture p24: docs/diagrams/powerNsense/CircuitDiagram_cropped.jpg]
Circuit Diagram


[Link For Complete Circuit Diagram](schemes/CircuitDiagram.png) 

[Link for all PCB KiCAD files](models/PCB)

---

## 3.5 Sensors

### 3.5.1 Sensor Placement Summary

| Sensor | Position | Height | Angle | Mounting Method | Justification |
|---|---|---|---|---|---|
| Camera Module 3 Wide | Rear-center, on pillar | 26 cm | 40 ° down | 3D-printed bracket on rear post | Forward view over chassis; avoids front blind spots; short CSI cable to RPi |
| VL53L4CD #1 | Front | 5.5 cm | 0° (horizontal, forward) | Recessed inside chassis body | Detects front parking wall at short range |
| VL53L4CD #2 | Rear | 6.7 cm | 180° (horizontal, backward) | Recessed inside chassis body | Detects rear parking wall at short range |
| VL53L4CD #3 | Left side | 5.5 cm | 90° left | Recessed inside chassis body | Left wall distance for lane positioning |
| VL53L4CD #4 | Right side | 5.5 cm | 90° right | Recessed inside chassis body | Right wall distance for lane positioning |
| BNO086 IMU | Center chassis | 11.6 cm | Flat  | PCB-mounted, close to center of gravity | Minimum vibration; accurate heading readings |

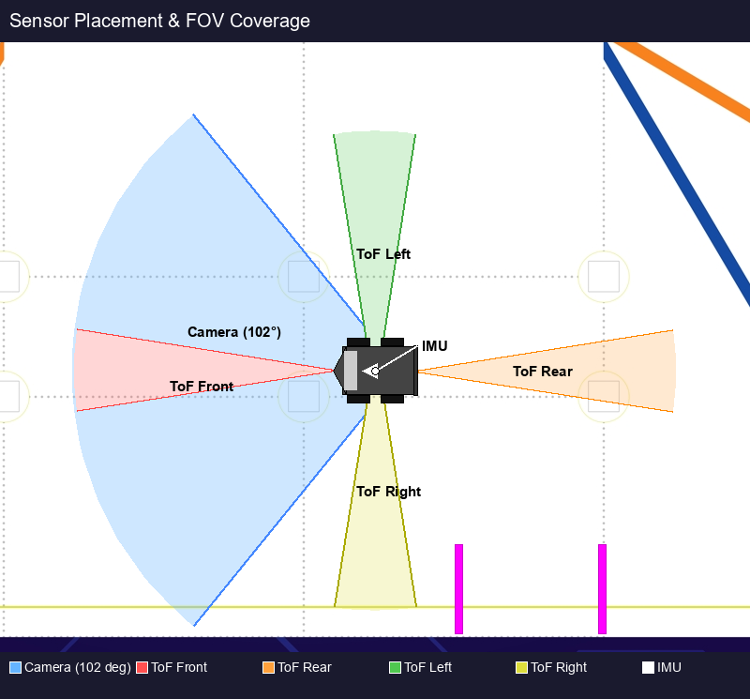
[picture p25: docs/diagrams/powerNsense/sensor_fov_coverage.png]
Sensor Placement


---

### 3.5.2 Camera

**Specification Comparison**

| Specification | Raspberry Pi Camera Module 3 Wide | Raspberry Pi HQ Camera + 180° Fish Eye lens |
| :---- | :---- | :---- |
| Resolution | 11.9 MP | 12.3 MP |
| Focusing | Auto | Manual |
| Field of View (FOV) | 120° Diagonal (102° Horizontal) | 180° Diagonal (180° Horizontal) |
| HDR support | Up to 3 MP, 30 fps | No |
| Aspect ratio | 16:9 (wider, optimized for videos) | 4:3 (squarish, optimized for still pictures) |

**Why We Chose Camera Module 3 Wide**

- The Camera Module 3 Wide provides auto focus which keeps moving targets sharp.
- The 120° FOV is sufficiently wide and at the same time gives zero edge distortion.
- The HDR would be useful for low light conditions if encountered.

**Experimentation**
- In the HQ Camera, objects towards the edges become curved and stretched, causing occasional failures in object contour detection. The distortion can be corrected, but the process is computationally intensive, reducing the control loop speed and slows down reaction time.
- In the HQ Camera, objects towards the edges seem compressed and smaller, causing contour area to drop below the detection threshold.
- The HQ camera was too heavy to be mounted at the rear top. Mounting it in the front lower center still covers the field due to its higher FOV, but it reduces the perception of depth as when mounted high, further objects appear higher up in the image but when mounted in front, all objects appear at a similar height.

|Camera Image from FishyEye Camera|Camera Image from RPi5 Wide Camera|
| :---: | :---:
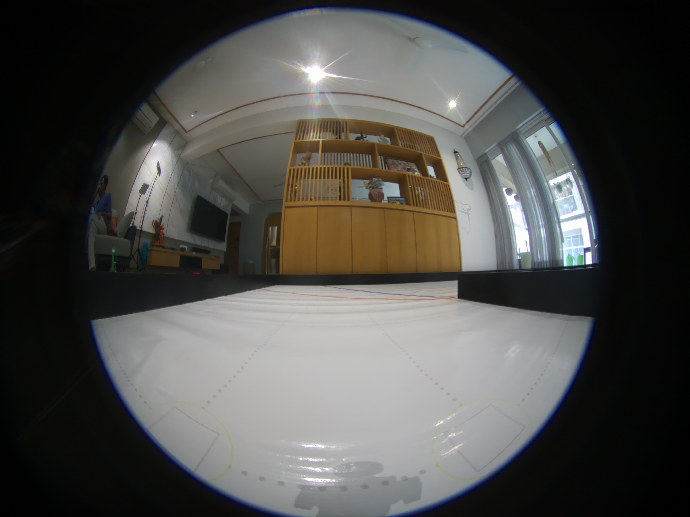
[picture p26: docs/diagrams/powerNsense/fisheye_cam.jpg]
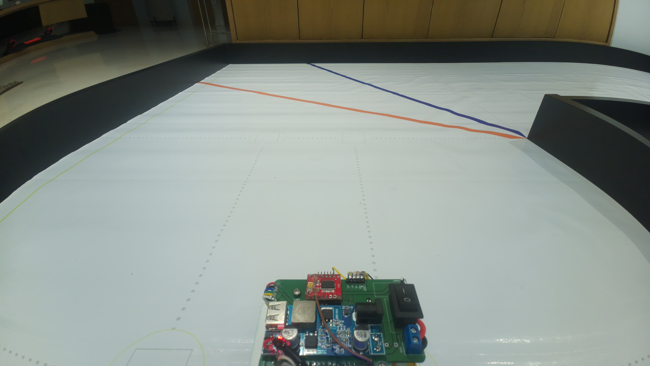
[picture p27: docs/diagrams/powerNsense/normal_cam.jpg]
|||

**Placement**

1) Mount the camera on the pillar
2) Adjust the camera angle so that the front edge of the robot is visible in the camera. This is essential to avoid blind spots in the front.
  
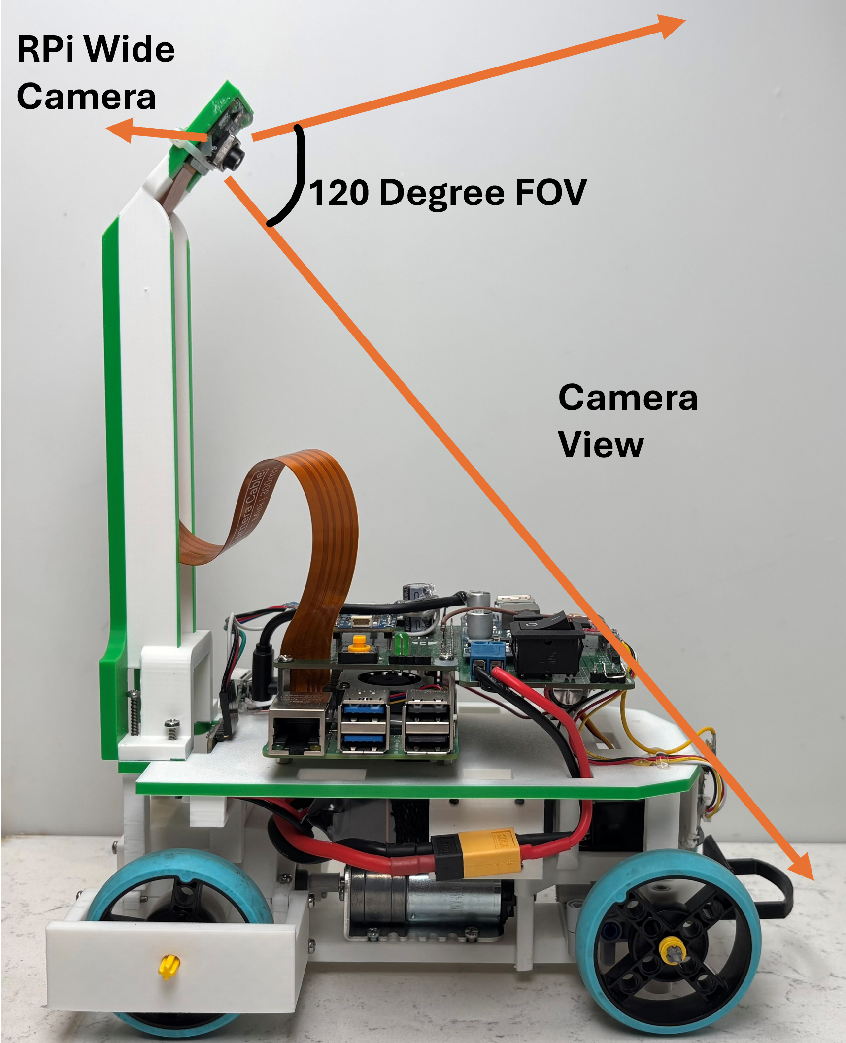
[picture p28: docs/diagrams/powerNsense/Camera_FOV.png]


---

### 3.5.3 Distance Sensor

**Specification Comparison**

| Specification | VL53L4CD | VL53L1X | VL53L8CX |
| :---- | :---- | :---- | :---- |
| **Zone Architecture** | Single Zone | Single Zone *(Programmable ROI)* | **Multi-Zone (4x4 or 8x8 grid)** |
| **Maximum Range** | Up to 1.3 meters (1300 mm) | **Up to 4.0 meters (4000 mm)** | **Up to 4.0 meters (4000 mm)** |
| **Minimum Range** | **Down to 1 mm** | ~40 mm | ~20 mm |
| **Field of View (FoV)** | 18° Diagonal | 15° to 27° (Adjustable via ROI) | **65° Diagonal** (Wide angle) |
| **Max Sampling Rate** | **Up to 100 Hz** | Up to 50 Hz | Up to 60 Hz |
| **Ambient Light Immunity** | Moderate | Standard | **Excellent** (Uses histogram processing) |
| **Primary Focus** | Ultra-short range precision & speed | Mid-to-Long range point sensing | Scene mapping, multi-target tracking |

**Why We Chose VL53L4CD**

- Our robot uses distance sensors for parallel parking — it must detect parking walls at very short range to avoid collision.
- We need high precision and accuracy at short ranges (down to 1mm minimum range).
- This model has a high 100 Hz update rate, providing faster reaction times compared to VL53L1X (50 Hz) and VL53L8CX (60 Hz).
- Its only disadvantage is its max range is 1.3m unlike others, but that is sufficient for our purpose since we only need to detect walls within parking distance.

**Experimentation**

To figure out the accuracy of our sensor at various distances, we measured its reading vs actual physical distance measurements.

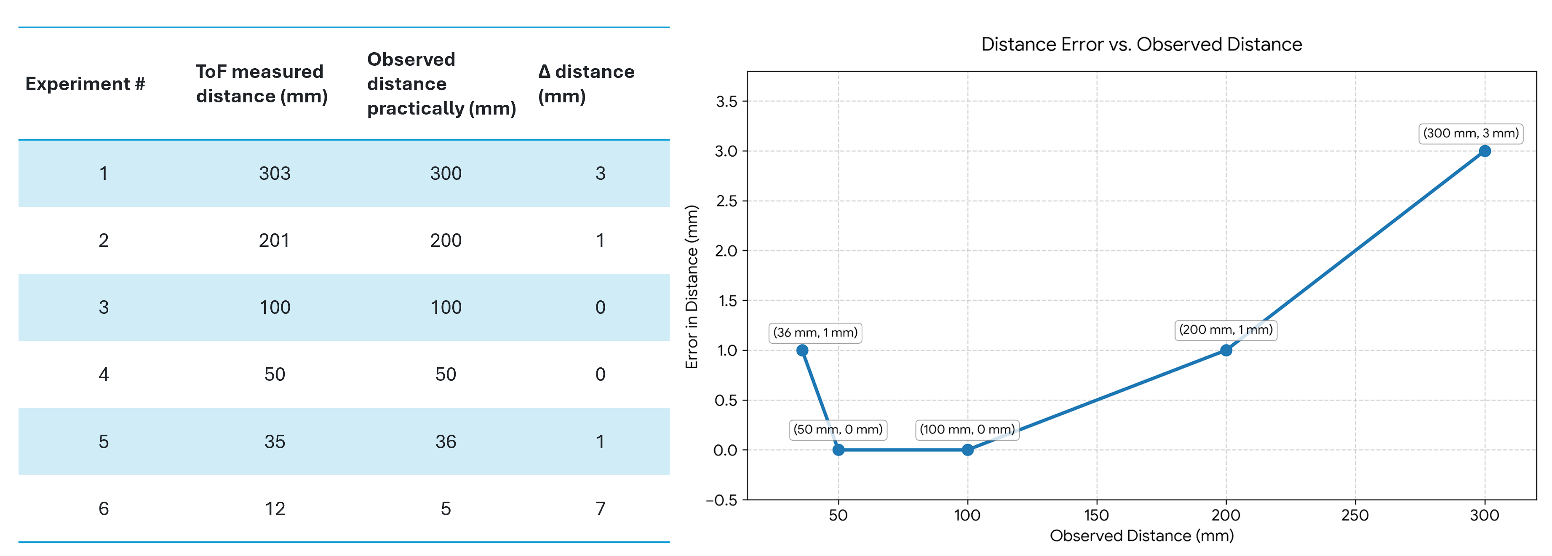
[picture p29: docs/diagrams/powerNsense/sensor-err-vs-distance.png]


**Conclusion** The accuracy of the ToF sensor reduces as the distance reduces with a possible blind spot. As a result, we refined our design by placing our sensors inside of the robot chassis to account for the measured blind spot.

**Placement**
Even though the VL53L4CD's datasheet mentions a minimum range of 1mm, its ranging error is higher at short distances of < 20mm. To avoid this issue altogether, we have mounted the sensor recessed inside the robot body on all sides, as much as we physically could. This ensures that the closest distance it needs to measure is more than 15 to 20 mm.

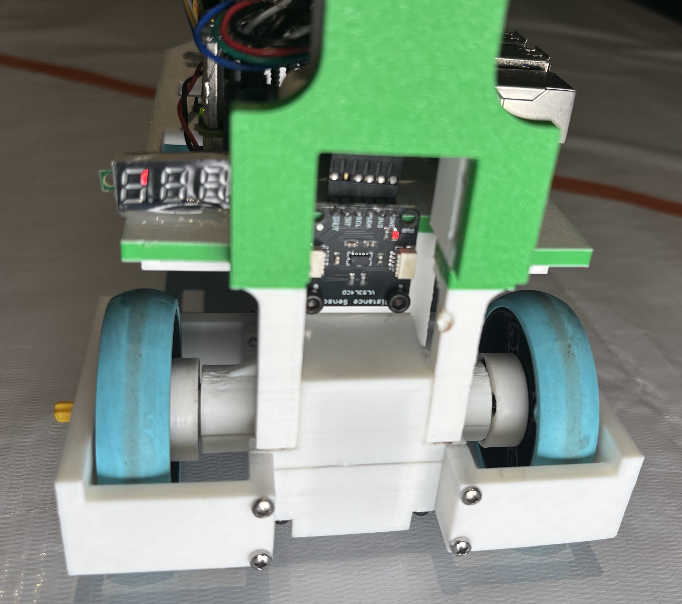
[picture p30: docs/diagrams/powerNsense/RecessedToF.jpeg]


---

### 3.5.4 IMU

**Specification Comparison**

| Specification / Feature | BNO055 | BNO086 |
| :---- | :---- | :---- |
| **Heading Drift** | High (drifts significantly; loses calibration by the 3rd lap) | Very low drift of 0.5° per minute with dynamic calibration |
| **Dedicated "Game Rotation Vector"** | No | **Yes** (6-DOF: Gyro + Accel) |
| **Hardware Tare (Zeroing)** | No *(Must manually calculate offset)* | **Yes** *(Native firmware command)* |
| **Calibration Architecture** | Continuous Background | **Initial Calibration + Runtime Stillness calibration** |

**Why We Chose BNO086**

- **Accuracy:** Very low drift of 0.5° per minute means the robot can make accurate parking maneuvers even in the 3rd lap.
- **Magnetic Immunity:** The Game Rotation Vector disables the magnetometer. This prevents the robot's heading from "jumping" when parking next to metal walls.
- **Alignment Ease:** Can issue a Tare command once the car is straight in the lane, instantly resetting heading to zero without manual offset calculation.
- **Field Adaptability:** BNO086 lets the host device tell the sensor its exact motion state to improve sensor accuracy by calibrating it for stillness before parking.

**Placement**

IMU is best placed at the center of the robot. We have tried to place it as close to the center as possible given the chassis and PCB limitations.

---

## 3.6 Microcontroller — Raspberry Pi 5 as Single Controller

We used Raspberry Pi 5 as the master brain for our robot. It single handedly manages the navigation loop and using the following important features we have eliminated the need for a co-processor.

* **Used RP1 Southbridge Chip as Hardware Co-Processor to Avoid OS Delays:** A standard Linux OS constantly pauses programs to switch between threads, which can cause skipped encoder pulses or stuttering motor signals. We solved this by offloading our low-level tasks to the Pi 5's built-in RP1 chip, which handles them at the hardware level.

* **Used RP1's Native Hardware PWM Channels for Stable Motor Control:** We connected our motor drivers directly to the RP1's built-in PWM channels. Because these signals are generated by dedicated hardware, they stay perfectly stable and jitter-free for smooth speed control without relying on the busy main CPU.

* **Zero Dropped Encoder Pulses:** We wired our wheel encoders into the RP1's Programmable I/O (PIO) blocks. These are independent hardware counters that run completely outside the main CPU, meaning they track every single pulse in the background with microsecond precision.

This design gave us the following **benefits**

* **Less Wiring and No Communication Lag:** By running everything on a single Raspberry Pi 5 instead of adding a secondary board like an ESP32, we simplified our electronics and saved space. This completely eliminated the data lag that usually happens when two different systems try to talk to each other.

* **Accurate Tracking Under Heavy Load:** Because the PIO silicon continuously counts and stores pulses in hardware buffers, we never lose track of our distance. Even when the main processor is heavily loaded with intense image processing tasks, the robot's navigation loop can just read the exact counts whenever it needs them.
---

## 3.7 Calibration Procedures

This section documents how each sensor is calibrated.

### 3.7.1 Camera HSV Threshold Calibration
We use [color_tuning.py](src/tools/color_tuning.py) for live trackbar-based HSV picker:
1. Power up robot on the actual mat under actual lighting
2. Run the tool — a window shows H/S/V sliders per color
3. Pan the robot across the mat so each pillar and line passes through the camera at real angles
4. Adjust bounds until the mask for each target is contiguous and black everywhere else
5. Copy final values into the `HSV_RANGES` dict in [tuning.py](src/obstacle_challenge/tuning.py) used by the main code.

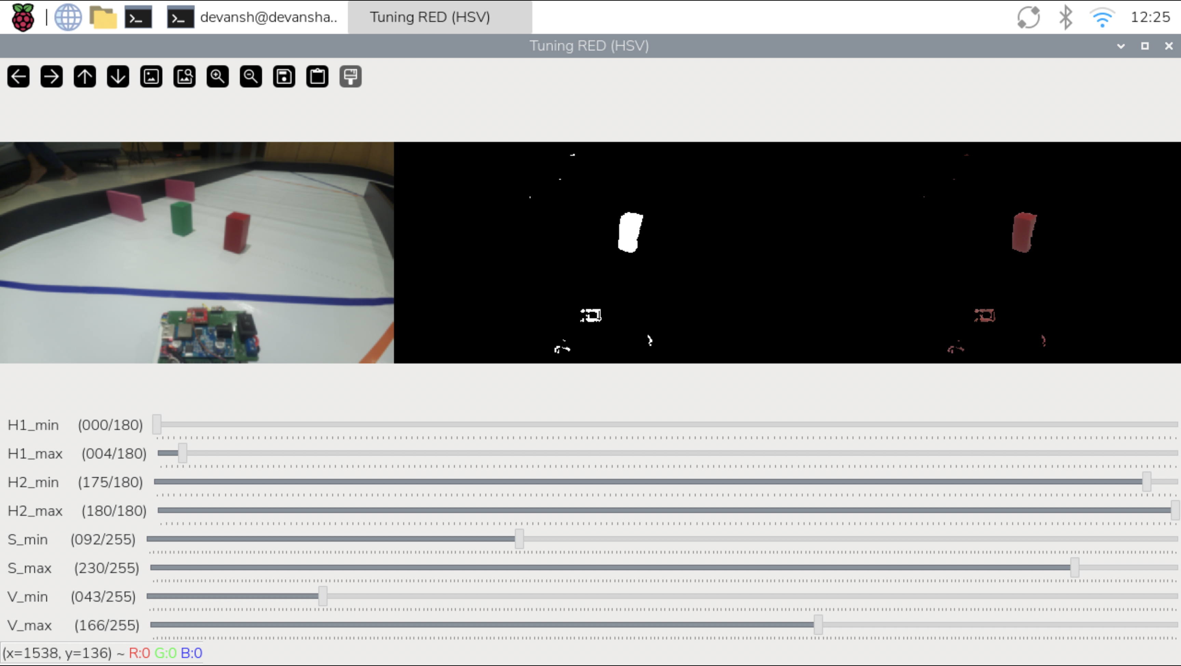
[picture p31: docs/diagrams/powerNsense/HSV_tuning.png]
HSV Tuning


**Key rule for BLACK tuning:** Keep S (saturation) low, not V. If you let S go wide, the dark blue mat and dark sides of red pillars get classified as wall, causing non existent walls in mid-corridor.

[Link for HSV Color Calibration Code](src/tools/color_tuning.py)

### 3.7.2 IMU Calibration
To calibrate the BNO086, we start by calibrating the gyroscope by keeping the robot still for 1 min. Then to calibrate the magnetometer, we rotate the robot in figure 8 shape. Lastly to calibrate the accelerometer, we keep it in 6 different position with each face pointing down.

[Link for IMU Calibration Code](src/tools/calibrate_bno.py)

### 3.7.3 Distance Sensor Calibration
For Distance calibration, we measure the distance of an object kept 20 cm away. The difference between actual and measured is used as offset in the code, so that software can handle the error created by the sensor reading. 

[Link To Experiment to measure Sensor Accuracy](#353-distance-sensor)

### 3.7.4 Encoder Calibration
Encoder was initially configured with a theoretical multiplier as per wheel diameter, gear ratio, pulses per rotation (ppm) to convert the encoder pulses to distance. This was slightly off so we adjusted the multiplier after running the robot for a fixed distance.

---

## 3.8 Failure Point Analysis 

This section details what can go wrong and what we do about it.

| Scenario | Impact | Mitigation |
| :--- | :--- | :--- |
| Lighting variations | Robot crashes into obstacles or wall | HSV tuning to adapt to new surroundings |
| Battery voltage drops | Robot slows down unexpectedly, LiPo could become permanently damaged if it goes below 3V/cell | Voltmeter added to make sure the robot voltage doesn’t go too low |
| ToF sensor dusty | Sensor gives false readings and increase in blind spot | Clean the sensor surface |
| IMU drift | Slanted parking or slanted path when going towards parking blocks | Magnetometer is turned off in IMU to reduce drift occurrences. Recalibrate IMU if it still drifts as per process described in this doc. |

---

## 3.9 Iteration Evidence

This section shows how the power/sensor design changed over time based on testing.

|Component|Iteration|Details|
|---|--|--|
|Camera|Mounting angle and height changed|[For Camera Mounts Iteration refer 3D Iterations](#551-3d-chassis-iterations)|
|TOF Selection| VL53L1X changed to VL53L4CD to reduce blind spot|[For TOF comparison refer section 3.5.3](#353-distance-sensor)|
|TOF Sensor|Mount position changed to recessed|[For TOF placement reasoning refer Section 3.5.3](#353-distance-sensor)|
|Battery|Lipo 11.1V 2100mAh changed to Lipo 11.1V 1500mAh after Power Budget calculation|[For Power Budget Calculation Refer to Section 3.1 ](#31-power-budget)|

---

# 4 Software Architecture & Obstacle Strategy

The WRO Future Engineers competition has two challenge rounds. Our software architecture handles both using common sensor and motor modules, with the obstacle challenge code being a superset of the open challenge.

| Mode | Entry Point | Purpose |
|---|---|---|
| **Open Challenge** | `src/open_challenge/main.py` | Three full laps on an empty track |
| **Obstacle Challenge** | `src/obstacle_challenge/main.py` | Three laps obeying red/green traffic signs + parallel parking |

Both modes share the same hardware-abstraction modules (`src/sensors/*`, `src/motors/*`) and follow the same architectural template — a multi-threaded sense/think/act loop running at ~50 fps on the Raspberry Pi 5. The obstacle code adds pillar-aware steering and parking on top of the same wall-following base.

**The arena:** A 3 x 3 m mat with movable inner walls, orange and blue floor lines marking each section boundary, and (in obstacle mode) red and green traffic sign pillars that must be passed on a fixed side, passing right from red,  and left from green. A magenta parking block marks the parking corridor where the robot must parallel-park after 3 laps.

---

## 4.1 Design Philosophy

We chose a **camera-first approach** for obstacle detection, a **multi-threaded architecture** for responsiveness, and **proportional control everywhere** for smooth driving.

- **Why camera-first:** The WRO track has colored pillars (red and green) that the robot must pass on specific sides. Only a camera can detect color at a distance. ToF sensors tell us how far walls are, but cannot tell us pillar color.
- **Why multi-threaded:** Reading the camera, IMU, and ToF sensors sequentially would slow the loop to ~15 fps. By reading them in parallel threads, the main loop gets fresh data every frame without waiting.
- **Why single RPi 5:** Instead of using a separate microcontroller for motor control, we use the RPi 5's RP1 hardware PWM and PIO blocks. This eliminates communication lag between two boards (see [Power & Sensor Architecture Section 3.6 for details](#36-microcontroller--raspberry-pi-5-as-single-controller)).
- **Why proportional control (not lane-switching):** Our earlier code in WRO 2025 used discrete lane-switching such as "if red pillar, move to right lane." This was brittle because gyro drift accumulates over 3 laps, and what the robot thought was "right lane" gradually drifted sideways. Our current code drives everything off camera-derived geometric error with proportional gains. Steering changes smoothly with the visual error, adapts continuously instead of waiting for a state change, and works regardless of where exactly a pillar is positioned.

### 4.1.1 Why We Rejected YOLO / Neural Networks

We considered training a YOLO classifier for shadow-robust pillar detection. We decided against it because:
- Annotation cost : even a few hundred labeled frames is several hours of work across lighting conditions
- Inference speed : YOLO on Pi 5 CPU will not hit our 50+ fps budget without adding a Hailo/Coral AI HAT (extra hardware, cost, power)

Instead we rely on tight HSV ranges, carefully placed ROIs, and the priority state machine, so classifier-grade discrimination is rarely needed.

---

## 4.2 System Architecture

### 4.2.1 Threading Model

Our software runs 4 background threads so the main navigation loop never waits on hardware. Each thread continuously reads one sensor and the main loop grabs the latest value whenever it needs it.

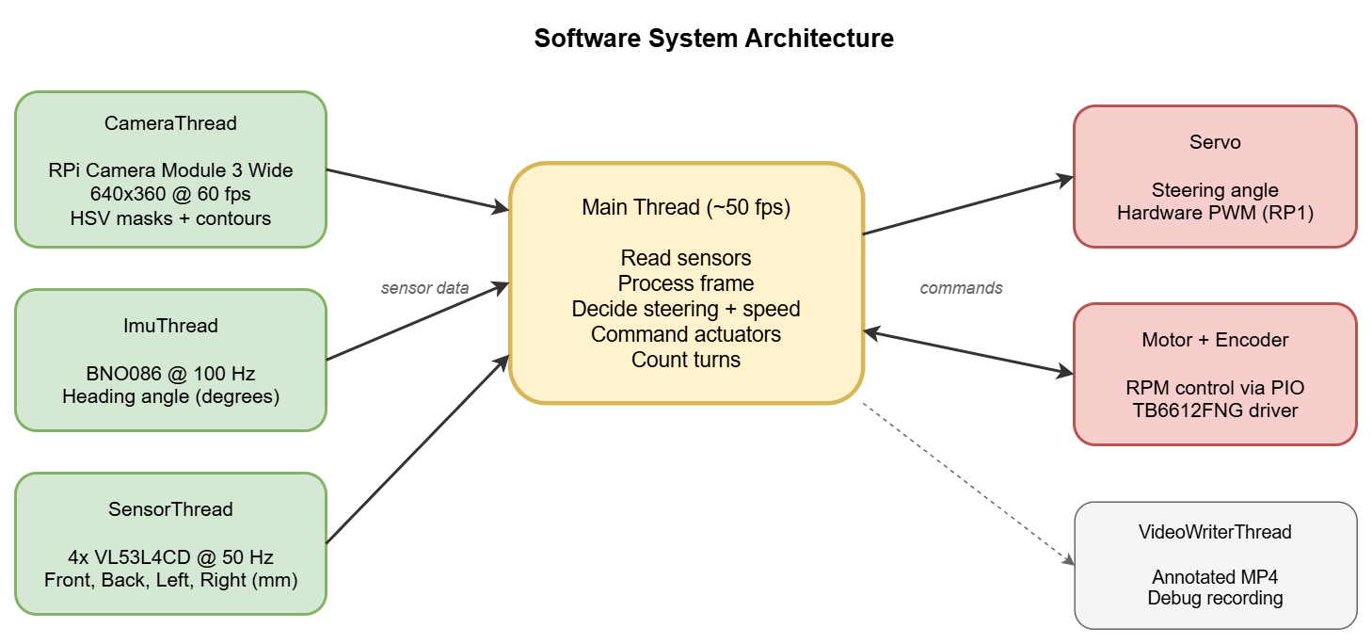
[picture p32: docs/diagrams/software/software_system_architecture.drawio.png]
System Architecture — Threading Model


### 4.2.2 Code Module Map
This is a high-level map of how files are organized within src folder.

```
src/
├── experiments/          # Standalone data-collection scripts for tuning/characterizing robot behavior
├── logs/                 # Logging setup/configuration for run logs
├── motors/               # Drive motor and steering servo control (PWM, RPM closed-loop)
├── obstacle_challenge/   # Obstacle Challenge entry point, config, and decision/control logic (includes a legacy subfolder)
├── open_challenge/       # Open Challenge entry point and config
├── sensors/              # Hardware-abstraction drivers for camera, IMU, distance sensors, and encoder (includes legacy subfolder)
├── threads/              # Background hardware-sensor thread management
├── tools/                # Calibration and diagnostic utilities (HSV tuning, capture pipelines, sensor tests)
└── vision/               # Shared frame-processing pipeline and worker pool
```

---

## 4.3 Open Challenge Flow Chart and Algorithm

The open challenge uses only the WALL FOLLOW and CORNER TURN behaviours from our architecture. With no traffic signs on the track, the robot drives three laps using the wall-following controller to stay centered, detects corners via the close-black ROI, and counts orange lines to know when 3 laps are complete.

The flow is 

1. **Initialize** : start camera and IMU threads, wait for button press, lock starting heading
2. **Drive** : motor at full speed
3. **Every frame (~60 fps):**
   - **Sense** : capture frame, detect walls on left/right and orange floor lines
   - **Decide** : balance wall areas to stay centered; if wall ahead, force a hard turn
   - **Act** : apply smoothed steering angle; count orange lines for lap tracking
4. **Stop** : after 12 orange lines (= 3 laps) and heading aligned with start → coast 0.8 s → brake

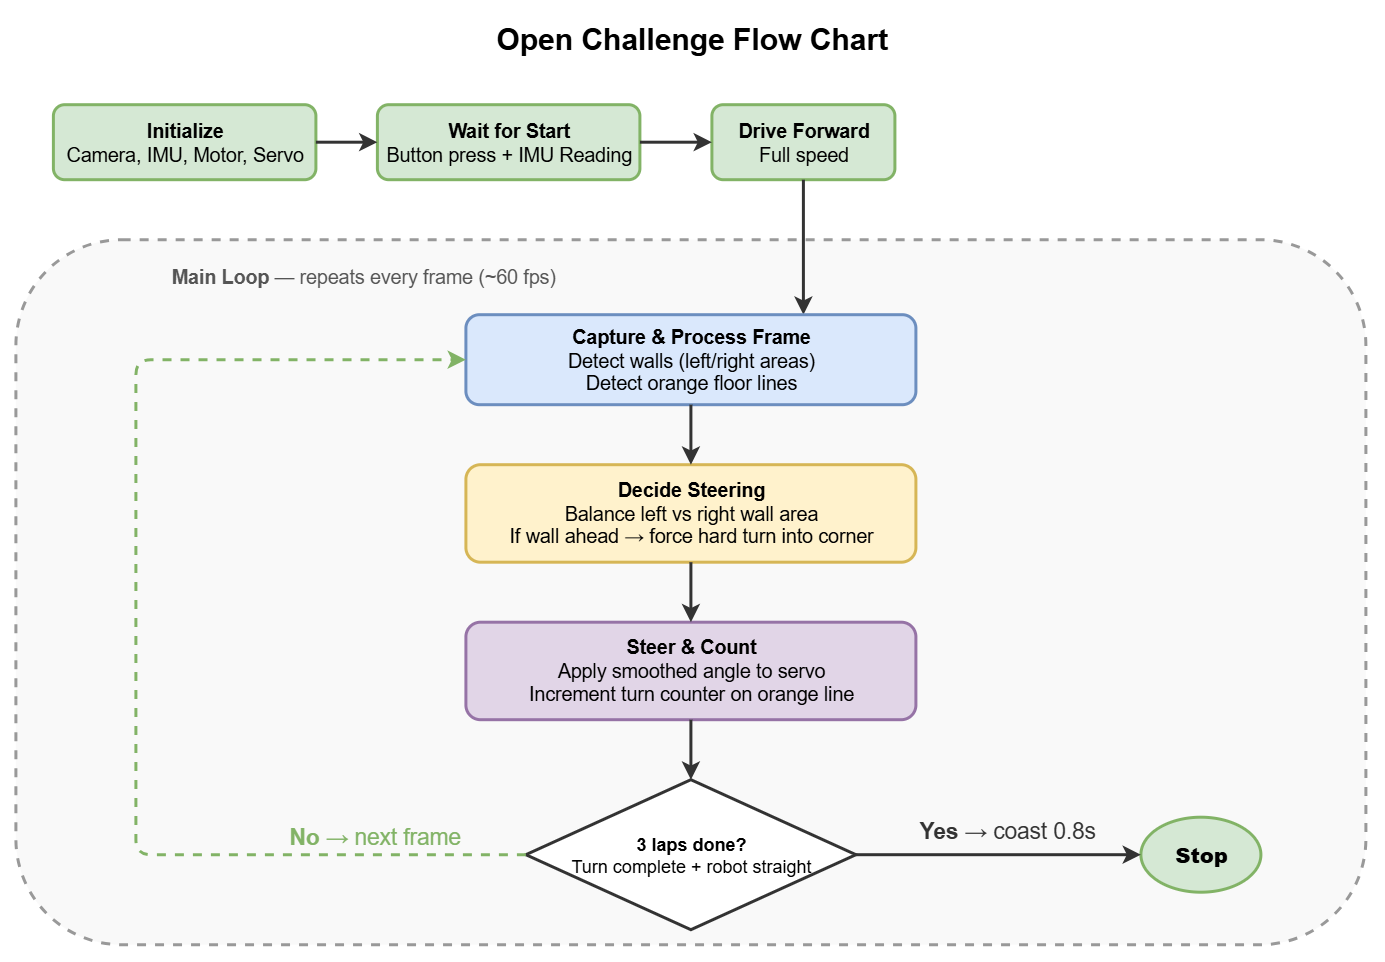
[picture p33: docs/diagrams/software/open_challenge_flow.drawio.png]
Open Challenge Program Flow


The same direction detection, turn counting, and performance optimizations described in later sections apply to both modes. The obstacle challenge code is a superset, adding pillar-aware steering (Sec 4.4.5) and parking (Sec 4.4.8) on top of this same wall-following base.

---

## 4.4 Obstacle Challenge — State Machine & Algorithms

The following sections describe the obstacle challenge, which builds on the open challenge core by adding a priority state machine for pillar avoidance and a parking routine.

**State Machine**

We implement a **flat priority state machine** that is evaluated fresh every frame. We chose this design because it makes the robot's behavior fully predictable from a single frame's sensor data — if you know what the camera and sensors see right now, you know exactly what the robot will do next.

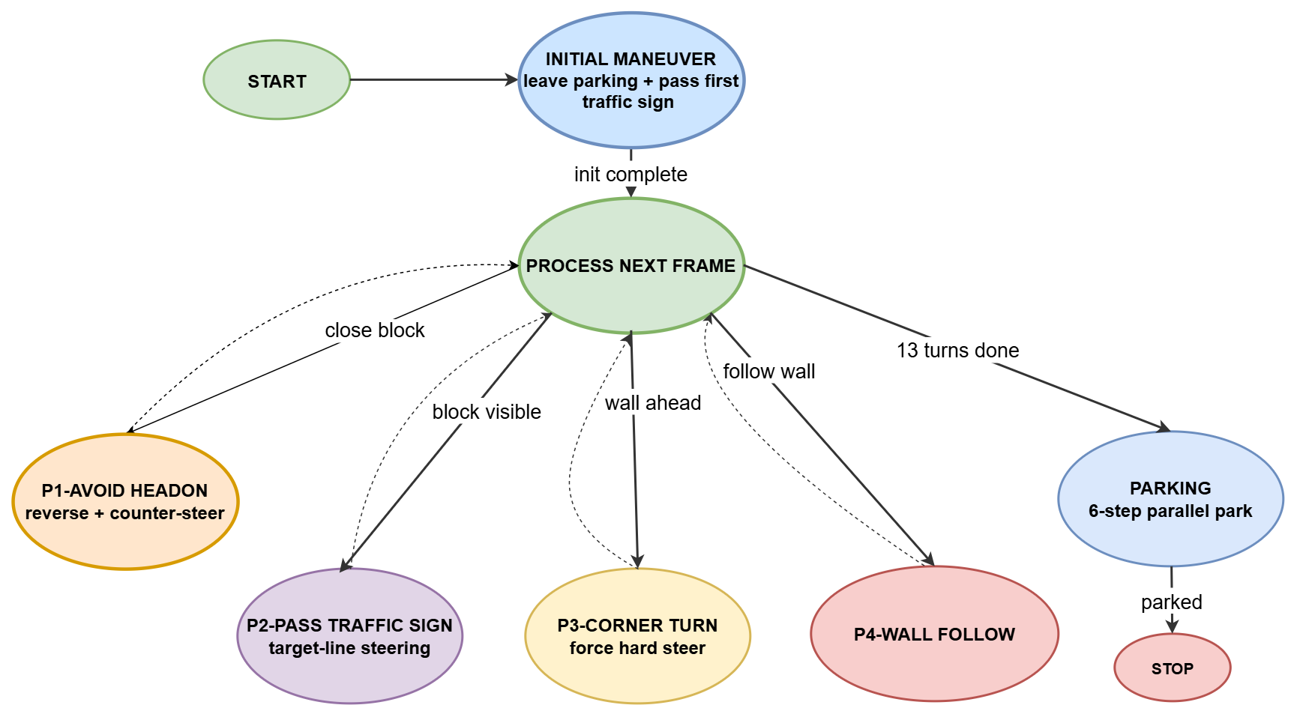
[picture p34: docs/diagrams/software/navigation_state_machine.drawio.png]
Navigation State Machine


### 4.4.1 States & Priority Order

| Priority | State | What the Robot Does | Entry Condition | 
|---|---|---|---|
 — | **INITIAL MANEUVER** | Detect direction, leave parking zone, and navigate past the first traffic sign | Race start (button press)|
| P0 | **PROCESS NEXT FRAME** | Capture a new camera frame, run the vision pipeline, and evaluate which priority state to enter | After INITIAL MANEUVER completes; re-entered every loop iteration |
| P1 | **AVOID HEADON** | Hard steer to ±35° to where there's more space | Close-black area exceeds 3000px threshold  | 
| P2 | **PASS TRAFFIC SIGN** | Target-line geometry steers the robot to keep right from red pillars and left from green pillars | Pillar detected in main camera frame |
| P3 | **CORNER TURN** | Forces a hard steer to turn into the corner |When one outer ROI drops below 100px | 
| P4 | **WALL FOLLOW** | PD controller balances left/right wall areas to keep robot centered in corridor | Default state when no higher-priority trigger fires |
| — | **PARKING** | 6-step parallel park using gyro + ToF + camera | Turn counter reaches 13 (3 laps complete) | 

When multiple triggers are true in the same frame, the highest priority wins. All states return to PROCESS NEXT FRAME after completion, except PARKING which leads to STOP.

### 4.4.2 INITIAL MANEUVER — Details

The INITIAL MANEUVER state runs once at the start of the race and handles three tasks in sequence:

**1. Direction Detection (camera-based):**
At startup, the robot determines whether the track is clockwise or counter-clockwise using the camera for first 10 frames:
- Left wall area > Right wall area → outer wall is on left → **clockwise**
- Right wall area > Left wall area → outer wall is on right → **counter-clockwise**

**2. Leave the Parking Zone:**
The robot starts inside the parking corridor against the outer wall. It must exit this corridor before the main navigation loop can begin. The robot undergoes a sequence of tuned steps to exit the parking in controlled manner.

**3. Navigate Past the First Traffic Sign:**
The first pillar can be directly in the robot path, after exiting the parking. To manage these situations robot has a pre-tuned instructions to pass the traffic sign as per its color and driving direction. Then the main loop takes over to generically handle traffic signs for next 3 laps.

---

### 4.4.3 PROCESS NEXT FRAME -Computer Vision Pipeline

The images below show what the robot's vision system does to each camera frame — from raw input to final detection output:

<table>
  <colgroup>
    <!-- Step 1-2 Columns -->
    <col style="width: 8%;">  <!-- Step -->
    <col style="width: 22%;"> <!-- What Happens (wraps tightly) -->
    <col style="width: 20%;"> <!-- Visual (larger share) -->
    <!-- Step 3-4 Columns -->
    <col style="width: 8%;">  <!-- Step -->
    <col style="width: 22%;"> <!-- What Happens (wraps tightly) -->
    <col style="width: 20%;"> <!-- Visual (larger share) -->
  </colgroup>
  <thead>
    <tr>
      <th>Step</th>
      <th>What Happens</th>
      <th>Visual</th>
      <th>Step</th>
      <th>What Happens</th>
      <th>Visual</th>
    </tr>
  </thead>
  <tbody>
    <tr>
      <td><strong>1. Raw Frame</strong></td>
      <td>Camera captures 640×360 image of the track</td>
      <td>
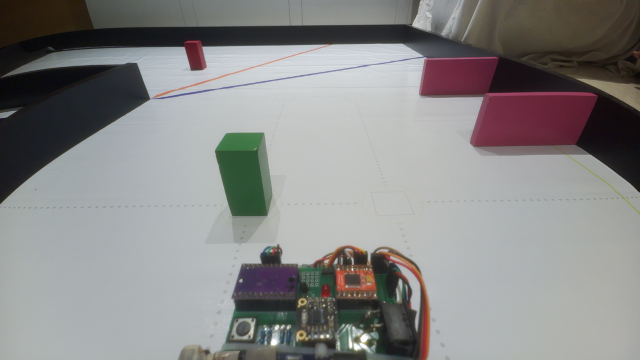
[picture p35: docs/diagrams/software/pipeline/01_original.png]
Raw Frame
        
      </td>
      <td><strong>2. Convert to HSV</strong></td>
      <td>Colour space that separates hue from brightness — makes colour detection lighting-robust</td>
      <td>
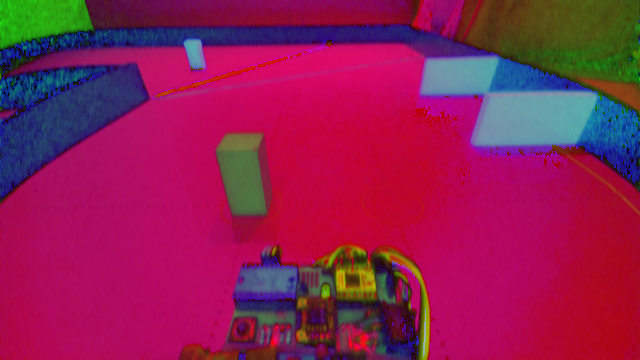
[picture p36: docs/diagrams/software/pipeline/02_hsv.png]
HSV Conversion
        
      </td>
    </tr>
    <tr>
      <td><strong>3. Colour Masks</strong></td>
      <td>Each colour gets its own binary mask (white = detected). Walls, pillars, and lines are isolated</td>
      <td>
        <div style="display: flex; gap: 4px;">
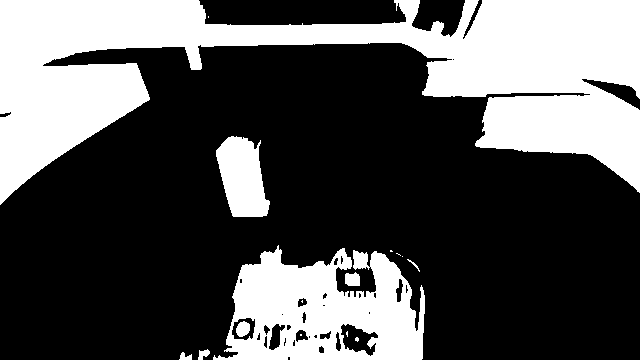
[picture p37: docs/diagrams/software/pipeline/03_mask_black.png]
Black Mask
          
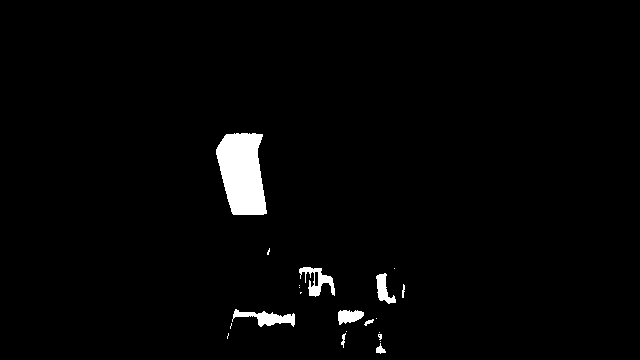
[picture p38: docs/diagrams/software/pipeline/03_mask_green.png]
Green Mask
          
        </div>
      </td>
      <td><strong>4. Detect & Annotate</strong></td>
      <td>Find contours in each mask → report position, area, and colour to the steering logic</td>
      <td>
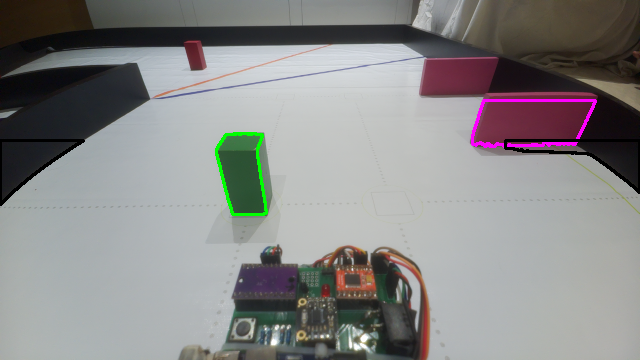
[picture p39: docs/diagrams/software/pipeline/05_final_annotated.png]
Annotated Output
        
      </td>
    </tr>
  </tbody>
</table>

**ROI Zones**

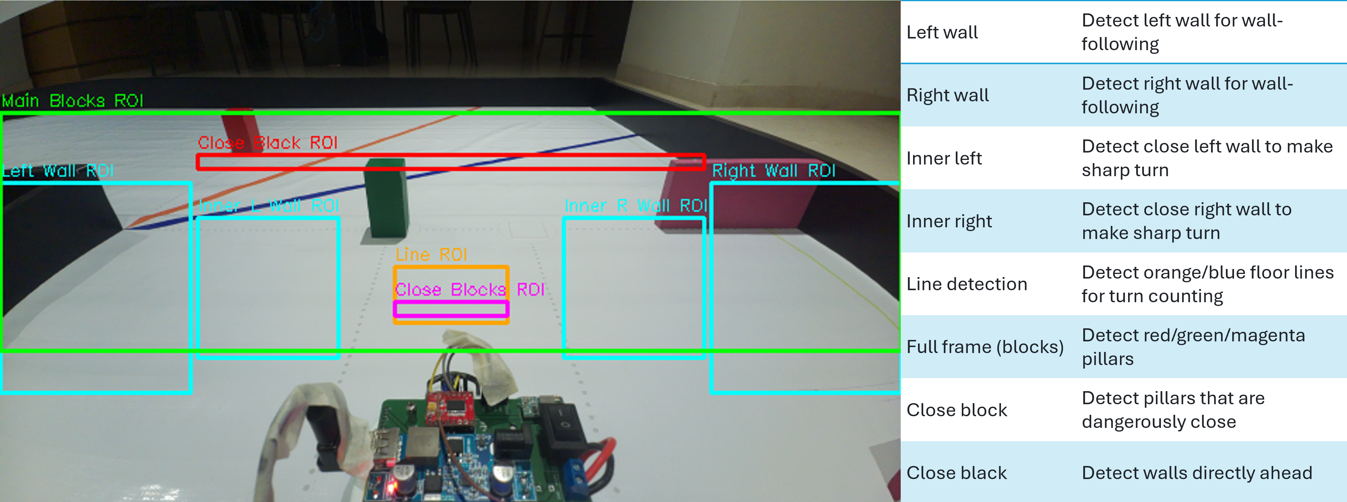
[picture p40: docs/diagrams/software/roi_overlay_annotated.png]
Camera ROI Zones


### 4.4.4 Avoid HeadOn 
If the total area in the close-black ROI exceeds 3000px, a wall is exactly in front. We hard steer to ±35° toward whichever side has more space. This is the only place the wall law ignores its own proportional output.

### 4.4.5 PASS TRAFFIC SIGN - Target-Line Geometry

**Goal:** Steer the robot to keep right from red pillars and keep left from green pillars.

**How it works:**

We define a virtual target line from a corner of the frame to the top center. The robot steers to bring the actual line towards the target line so the pillar stays on the correct side.

Target-Line Geometry Diagram

**Per-frame Steering angle calculation**

```
current_angle = atan2(block_x - origin_x, origin_y - block_y)  // θ = tan_inv(Δx/Δy)
steering_angle = (current_angle - IDEAL_ANGLE) * Kp

where
IDEAL_ANGLE(red) = +42.5 degrees  // tuned for red pillar
IDEAL_ANGLE(green) = -40.5 degrees  // tuned for green pillar
Kp = 1.5  // proportional constant
```

**Evaluation of multiple algorithms**
Our previous year's robot used a **fixed vertical line** as the target line and actual line. If you notice the camera image, the straight walls are seen in camera as inclined lines which means the straight path of robot visually appears as inclined lines due to the depth of vision. Fixed line caused the block to come very close to the robot and to avoid this, we used to change the target line when block used to come very close which was a hacky approach.

Inclined line using angle calculation for **Target line geometry** causes the delta between target and actual to remain almost constant even when the robot approaches the pillar. The robot now steers smoothly like a real world driver would avoid an obstacle. The code is cleaner as there aren't any hacky approaches now making it reliable.

We built a **calibration tool** (`drive_straight_tune_target.py`) that drives the robot straight past a pillar while tracking its centroid frame-by-frame. The path the centroid traces is **not vertical** — because of the camera's forward tilt, a fixed pillar drifts horizontally across the frame as it gets closer. The angle-based law accounts for this drift naturally, making the robot pass cleanly at every range.

**Edge Cases**

**Inner-wall guard:** When `wall_inner_right > 3000` (or left), the block-following angle is clipped to a one-sided range so steering can only turn further *away* from the wall, never into it. This prevents wall contact when passing a pillar near a corner.

**Magenta-coordinated path:** When a magenta parking block is visible alongwith a pillar, the steering target becomes the midpoint between them which allows us to ensure we do not hit any of the blocks.

**Close Block Avoidance Pillar:** If a pillar gets dangerously close (in the "close block" ROI), normal steering cannot avoid it. We do a hard reverse maneuver.

**Close Block Avoidance Magenta Parking:** Magenta close-blocks are only treated as evasion targets after 5 seconds from race start. Early magenta near the camera is the parking corridor entrance, which we don't want to dodge.

### 4.4.6 Wall Following — PD Controller

**Goal:** When no pillars are visible, keep the robot centered between the left and right walls.

**How it works:**

We use **four ROIs, not two.** Each side of the frame is split into an outer band and an inner band:
- **Outer ROIs** (x: 0..135 and 505..640) sit near frame edges — they feed the wall-balancing law as a simple area difference
- **Inner ROIs** (x: 140..240 and 400..500) sit closer to frame center — they detect a wall that is dead ahead and very close

**Why inner ROIs matter:** When the robot rounds a corner, the far wall slides out of view. If only outer ROIs existed, the area difference would go to zero and the robot would drive straight into the corner wall. The inner ROI catches the close wall and triggers a forced turn before contact.

**Formula:**
```
left_area = wall_left_outer + wall_inner_left
right_area = wall_right_outer + wall_inner_right
wall_error = left_area - right_area
angle = wall_error * Kp + wall_derivative * Kd + bias

Where:
  Kp = 0.0006
  Kd = 0.0003
  bias = +1 (constant offset)
```

### 4.4.7 Corner Turns and Lap Count Logic 

**Corner Turn**

When one outer ROI drops below 100px while the opposite side still sees a wall, the robot is entering a corner. We amplify the remaining wall area (2x + 25000) to force a harder turn into the corner instead of understeering.

**Lap Count Logic**

Count orange floor lines to know when 3 laps (12 turns) are complete.

**How it works:**
- Each frame, check if orange is detected in the line ROI
- Store last 4 detections in a queue: `[oldest, ..., newest]`
- Count a turn ONLY when pattern is `[False, True, True, True]` — a fresh rising edge that persisted for 3 frames
- After counting, apply 50-frame cooldown (prevent double-counting the same line)

**Why did we do this?** At high speed, a single orange line stays in the ROI for ~10 frames. Without the 4-frame rising-edge check and cooldown, one line could be counted multiple times.

### 4.4.8 Parking Algorithm

After completing 3 laps (12 turns), the robot enters the parking sequence. We have two versions: `parking()` for clockwise and `parking2()` for counter-clockwise tracks. The robot uses the IMU for precise turns and small segments of straight driving during parking manuevers.

**Parking Phases (Clockwise Example)**

Parking Sequence Phases

| Phase | Action | End Condition |
|---|---|---|
| 1 | Drive forward till orange line | Encoder distance reached (14 cm) |
| 2 | Reverse at -60° steering, heading → INITIAL+90° | Back ToF < 130mm (near outer wall) |
| 3 | Drive forward along wall, camera-based wall-following (Kp=0.8), count magenta pillars | 2nd magenta pillar passed + 0.62s coast |
| 4 | Steer into parking at +55°, heading → INITIAL+100° | Back ToF < 160mm |
| 5 | Forward/reverse manuever to align parallel | Back ToF ≤ 95mm AND heading ≈ INITIAL±180° |

**Parking Sensors Used**

- **Back ToF:** Knows when robot is close to rear wall of parking slot
- **Center ToF:** Monitors distance to wall during corridor driving
- **IMU heading:** Controls all steering angles precisely
- **Camera:** Follows black wall edge during Phase 3, counts magenta pillar passes

**Goal:** Use the IMU heading to maintain a straight line or execute precise turns.

**IMU Code Reference:**
```
heading_error = target_heading - current_heading
steering = heading_error × Kp

Where:
  Kp = 0.85 (normal driving)
  Kp = 1.0 to 2.0 (parking maneuvers)
```

The gyro handles 360° wrap-around: if the error is > 180°, it wraps to the shorter direction.

Used for:
- Keeping straight during initial maneuver
- 90° turns at corners
- All parking phases (precise angle targets)

---

## 4.5 Edge Cases
| Edge Case | What Could Go Wrong | How We Handle It |
| :--- | :--- | :--- |
| **Same frame processed twice** | Waste processing time | Skip frame if `frame_counter` unchanged |
| **Magenta parking block during startup** | Robot reversal within parking section | 5-second gap on startup before close block reversal activates for magenta parking blocks |
| **Inner wall very close during block follow** | Robot crashes into wall | Servo angle clamped to steer away from wall |
| **Close black wall ahead (no blocks)** | Crash into front wall | If `close_black_area > 3000` → force ±35° turn based on direction |
| **Block disappears mid-avoidance** | Sudden speed change | Grace frames: hold last block speed for 5 frames after block disappears |
| **Wheel stall (blocked/stuck)** | Robot stops moving | RPM controller detects zero RPM → stall recovery |
| **No walls visible, but orange/blue line visible** | Robot will not turn and crash | Force ±35° steering based on track direction |
---

## 4.6 Parameter Tuning

### 4.6.1 All Control Parameters
All tuned paramters are cleanly organized and available in 

[Open Challenge Tuned Parameter List](src/open_challenge/config.py)

[Obstacle Challenge Tuned Parameter List](src/obstacle_challenge/config.py)

### 4.6.2 Tuning Process

**Target Line Tuning** Look at the video to see if the robot is oscillating a lot. If it's oscillating too much, increase the Kd. If it takes too long for the target and actual lines to coincide, increase Kp

**Wall Following Tuning** For wall following, look at the robot, and if it is taking too slow turns, then increase the Kp. If it is oscillating wildly, reduce Kp and increase Kd. If it is oscillating mildly, then increase Kd. If it is overturning, decrease Kp

---

## 4.7 RPM Control — PI Controller with Feed-Forward

**Goal:** Maintain consistent wheel speed regardless of load (turns, inclines, battery sag).

**How it works:**
- Motor encoder counts pulses via RP1 PIO
- Actual RPM is compared to target RPM
- PI controller adjusts PWM duty cycle

```
Target RPM = 0.85 * MAX_WHEEL_RPM (normal driving)
Kp = 0.20
Ki = 0.50
Ramp limit = 25 RPM increase per frame (prevents wheel spin)
```

**Variable Speed near obstacles:** When a pillar is visible, the target speed is reduced proportionally to how close the pillar is. Pillar at top of frame (far) → 85% speed. Pillar at bottom (close) → 60% speed.

### 4.7.1 Why PIO for the Encoder

The wheel encoder is a quadrature pair driven through the **PIO block** on the RPi 5's RP1 I/O controller. PIO is a small, deterministic state-machine engine sitting next to the main CPU — it handles encoder pulses entirely in hardware while the CPU does nothing.

**Why this matters:** Linux is not a real-time OS. The scheduler can preempt our Python loop for tens of milliseconds. If we counted encoder edges from Python, every preemption gap would silently drop counts and reported distance would drift. The PIO state machine sits *outside* the Linux scheduler and **never misses a count** regardless of CPU load.

Two modes of operation:
- `motor.start_rpm_control(target_rpm, direction)` — frives the robot at target RPM (most commonly used)
- `motor.move(distance_cm)` — PID loop that ramps speed up, then decelerates as encoder approaches target distance (used in special situations)

### 4.7.2 Control Loop Diagram

RPM Control Loop — Encoder and Motor Interaction with RPi 5

*Closed-loop RPM control showing the PI controller running on the RPi 5 CPU, with the RP1 PIO block handling encoder counting in hardware. The feed-forward path sets the initial PWM, and the PI corrects for load disturbances.*

---

## 4.8 Testing Results

In order to test all tough combinations we wrote a program that could create the field settings for the tough combinations using the [generate_tough_configs.py](test/generate_tough_configs.py). For consolidation we used the format as in [PDF](test/WRO_FE_2026_Master_Test_Tracker_v2.pdf) 

Here's one of the sample runs for Obstacle challenge :

Test observations

---

## 4.9 Performance Optimizations

These design choices keep the loop running at 50+ fps on a Raspberry Pi 5:
* **Operate on cropped frame:** Crop the frame before performing BGR to HSV conversion. This saves 30% of conversion cost, and the stripped-out top/bottom rows are irrelevant for robot navigation.
* **Skip processing empty masks:** Check if a mask is empty using `countNonZero` before finding contours. Most color masks are empty, saving significant time if processing is skipped.
* **Process a smaller frame:** Process a 640x360px image instead of 2304x1296 (10 times fewer pixels to process).
* **Multiprocessing:** Utilize all 4 cores on the RPi5 to reduce workload by having one core process black masks while another handles color masks.
* **Update servo angle only if changed:** Check if the servo angle has changed from the last frame; only command the servo to move if an actual change occurred.

---

## 4.10 Troubleshooting and Debugging

Every run writes a self-contained folder with:
- Annotated MP4 (ROIs, contours, target lines, FPS, turn counter, computed angle)
- Full stdout/stderr log (state transitions, ToF readings, heading deltas)

This allows post-run analysis to fix the issue observed in the prior run.

---

# 5 Systems Thinking & Engineering Decisions

This section looks at the robot as one system that combines mechanical, electrical and software aspects. Mobility Management, Power and Sensor Architecture, and Software Architecture each explain why a specific component or algorithm was chosen in isolation. This section looks at the places where a decision in one area forced something in another. We discuss the constraints all three subsystems share, the trade-offs we only discovered once the full robot was tested together, and the failures that needed more than one round of debugging to actually fix.

## 5.1 System Overview
This system diagram illustrates how power, data, and mechanical dependencies actually flow between subsystems on the robot.
- Power subsystem provides power to the circuitry across two power rails - 5V and 12V.
- Sensors sense the environment and provide signals to the Software.
- Software processes what the sensors see and makes the robot think before taking actions.
- Mobility acts upon the software signals and executes the physical movement.

**Here is a sample cycle**
- The camera sees the surroundings and provides raw frames to Rpi5
- The encoder provides pulses to the RP1 controller which provides the accumulated counts to Rpi5
- The software does image processing to determine which state it is in and decide on the robot movements
- The software provides appropriate PWM signals for the servo motor and the drive motor to the RP1 controller
- The RP1 controller provides the signals to the servo motor and to the motor driver.
- The motor driver passes on appropriate external voltage as per PWM signal to the motor.

Greenbotics System Integration Diagram

*Purple boxes are Power & Sense — battery, converters, camera, IMU, ToF, and encoder. Yellow boxes are Software — the Raspberry Pi 5, its six threads, and the vision pipeline. Red boxes are Mobility — the driver, motor, differential, servo, and steering. The dashed green box is the RP1 I/O controller, hardware inside the Pi that runs PWM and pulse-counting without using the CPU.*

---

## 5.2 Shared Constraints

A few constraints don't belong to any single subsystem. They impact the robot's design across subsystems.

### 5.2.1 The no-differential-drive rule

WRO's rule against a differential-drive robot is the constraint for multiple aspects:

Mobility: It pushed us towards a front-steering vehicle. For a front steering vehicle, the parallel parking requirement makes turning radius dictate the length of the chassis (R = L / sin(θ)). The outer radius grows further with the width (R(outer) = R(center) + W/2). Hence we tightly packed back to back the differential, drive motor, and steering assembly, building a compact robot

Power: The power and PCB components also need to be tightly packed to fit this compact sized robot.

### 5.2.2 Vehicle weight

The vehicle weight should be within 1.5 kg as per the rules. However it's not just the total weight that matters. How this weight is distributed is equally important. The battery could have been placed on top of the plate to make charging and swapping easier, but we placed it on the bottom plate to keep the centre of mass as low as possible. This gives better stability to the robot especially during sharp turns. We also have kept the weight as low as possible. This helps in multiple aspects:

Mobility: A lower weight robot requires a motor with lower power.

Power: A lower power motor requires less battery power to drive, hence smaller battery

### 5.2.3 Power budget

The full power budget identified in Power and Sensor Architecture gives us a runtime of over an hour. Building a robot within this constraint also impacted

Software: The image detection algorithm could have been improved with YOLO, but it would have required an AI HAT on the Rpi increasing the power budget further, which would require a higher powered battery, hence increasing the weight.

Mobility: A higher weight slows down the robot.

Thus multiple decisions are interlinked. Hence we limited ourselves to a software algorithm that could run on the Rpi5 itself.

### 5.2.4 Control Loop timing

The robot sense - think - act control loop needs to be really fast to make quick decisions the moment it sees things else the robot may bang into obstacles or the wall. This single constraint dictates:

Software architecture: If we collect the sensor data in the main control loop, it would slow down the system drastically. We run a multi threaded system where dedicated threads collect & process the Camera frames, IMU readings, Sensor readings. This keeps the control loop free to think and act efficiently. While the main thread is doing this, the other threads collect and process the data in parallel. This architecture works because Rpi 5 has a quad core CPU where 4 threads can run in parallel.

Power and Sensor architecture: Sensors need fast sampling rate to be able to quickly feed back changes in distances during parking to take advantage of a fast control loop. Similarly, a camera with a fast fps would feed back environment changes rapidly.

Mobility: The servo motor needs fast reaction time so that it can quickly act on the steering instructions.

---

## 5.3 Cross-Subsystem Decision Case Studies

These are decisions that cannot be fully explained from inside a single subsystem document — each one only makes sense once you look at what two or three subsystems needed at the same time.

### 5.3.1 One Raspberry Pi 5 instead of a dual-controller architecture

We used RP1, the Rpi's onboard IO controller to provide jitter free PWM output and accurate Encoder pulse counts. This avoids the typical scheduling jitter associated with offloading these to a separate thread on Linux.

The alternative to use a second microcontroller dedicated to motor tasks was rejected because of the native features of Rpi 5.

The decision is a systems decision, because three different constraints point the same way:

* **Mobility** needed precise encoder counting for sensitive parallel parking maneuvers. Losing pulses during micro-adjustments would make parking difficult.

* **Power and Sensors** had fewer boards to wire, power, and mount.

* **Software** needed the control loop to run at fast fps. An onboard controller avoids the lag associated with cross-board communication.

Using the Rpi 5's RP1 controller answers all three at once: it counts every encoder edge in the onboard controller regardless of CPU load, hardware PWM never stutters even when the vision pipeline is busy, and there is only one board's worth of wiring and power distribution.

### 5.3.2 Speed vs. accuracy — why we moved to variable speed

**Trigger:** Increasing the drive speed from 60% to 85% kept accuracy at the same 100% across 5 runs each. The robot avoided all obstacles in both scenarios. But the overall lap time got worse, not better, despite the higher speed.

**Diagnosis:** At 85% speed, the robot was reaching pillars before it could be finished steering to the correct side, triggering the close-block emergency evasion routine more often than at 60%. Each evasion is a full stop-reverse-recover cycle, and costs more time than the higher speed saved.

**Decision:** We wanted higher accuracy at higher speed. So moved to variable speed. The robot goes on full speed while the path is clear, reducing speed as a pillar gets closer. This means the robot goes slower only when it's needed. **Exactly like a real world car driver would slow down near obstacles instead of everywhere.**

**Verification:** Variable speed produced a faster overall lap time than either fixed-speed setting.

| Scenario | No. of backoffs (avg) | Time taken in seconds (avg) |
| :---- | :---- | :---- |
| 60% fixed | 0-1 | 51 |
| 85% fixed | 3-4 | 59 |
| Variable speed | 0 | 50 |

This result matches the experiment we did in Mobility Management that concluded the reaction time to stop the robot in front of an obstacle at a given distance increases with speed.

---

## 5.4 Risk & Failure Modes

This section outlines the engineering process we followed when the robot broke mid-project. These failures needed debugging across multiple aspects of the system, sometimes software, sometimes hardware and sometimes both!

### 5.4.1 Drive motor burnout — TT-GM25 to Pololu 4861

**Trigger:** The TT-GM25 drive motor began stalling intermittently, initially once in a few days, then finally four times during a single run.

**Diagnosis:**
**1)** We put a multimeter across the driver output when the robot stalled four times and noticed it was getting 6.5V. This confirmed that software and wiring was fine.

**2)** The motor terminals still showed continuity with occasional breaks.
**3)** We opened the motor casing and found dark marks on the steel shaft that remained even after cleaning it, probably signs of physical wear inside the motor.

Greenbotics System Integration Diagram

**Alternatives considered:** Replace it with another TT-GM25 of the same design, which repeats the same risk.

**Decision:** We moved to a motor from a reliable brand instead of staying with the same design, and reused the speed/torque comparison from Mobility Management section to pick the Pololu 4861 specifically, rather than just any Pololu model.

**Verification:** The Pololu 4861 has run for over a month of testing with zero stalls, against a TT-GM25 that was already failing within weeks.

### 5.4.2 ToF sensor dropout during parking

**Trigger:** Roughly once in every 20 parking runs, the robot failed to stop during a parking maneuver and hit the wall instead of braking.

**Diagnosis:** Run logs showed the distance sensor reading None at the moment of failure. This confirmed that the sensor was not responding and it wasn't a logic error in the parking routine.

**Alternatives considered:**

**1)** We assumed initialisation failure at startup time, so added a retry until successful check during the sensor initialisation at startup. Still it failed, implying that sensor was starting successfully, but dropping out mid run.

**2)** We added a fallback initialisation during sensor reads. If a sensor failed in the middle of a run, it would be re-initialised. Still it failed, confirming this wasn't a software problem.

**3)** The actual cause turned out to be hardware. The Raspberry Pi GPIO pin driving that sensor defaults to an internal Pull-Down, while the sensor needs a Pull-Up.

**Decision:** Reconfigured the GPIO pin as Pull-Up in the Pi's config.

**Verification:** Zero recurrence over 200+ runs against a roughly 1-in-20 failure rate inspite of the two software-level fixes.

### 5.4.3 Wheel wobble showing up as camera jitter

**Trigger:** No wobble was visible in the robot's physical driving, but the camera feed showed a wavy motion while the robot was moving.

**Diagnosis:** Traced to the wheel-axle fit inside the 3D-printed gearbox, which does not hold the wheel centred as precisely as the Lego chassis it replaced. That play was too small to notice by watching the chassis, but was visible when closely observing the shaft. This is amplified as the camera is mounted higher up on a pillar.

**Alternatives considered:** A software correction would have increased the main loop processing time, besides the issue wasn't significantly affecting driving.

**Decision:** Tried to fix it mechanically by adding a plastic bracket fixed with the gearbox that supports the wheel with a second axle point.

<table style="width: 100%; text-align: center; border-collapse: collapse;">
  <tr>
    <th>Wheel Bracket (Back)</th>
    <th>Wheel Bracket (Side)</th>
  </tr>
  <tr>
    <td style="padding: 10px;">
      Wheel Bracket Back
    </td>
    <td style="padding: 10px;">
      Wheel Bracket Side
    </td>
  </tr>
</table>

**Verification:**

A comparison of the videos before and after the fix shows some improvement in wobble, though it is not completely eliminated.

|Before|After|
| :---: | :---:
|Before|After|

---

## 5.5 Iteration and Testing Cycle Summary

### 5.5.1 3D Chassis Iterations
We have worked on this robot since Jan 2026 and gone over multiple iterations with respect to various components. These changes required changes to the 3D parts as well and we designed multiple variations of each of our chassis parts to accommodate these changes.

3D Graveyard 1

3D Graveyard 2

### 5.5.2 Other Design Iterations
Pulled from all three subsystem documents plus the case studies and failures above, this table is a compact record of what changed, why, and what evidence backs the change.

| Decision | Changed From → To | Why | Evidence / Status |
| :---- | :---- | :---- | :---- |
| Steering | Parallel → Ackermann | Tyre slip during tight maneuvers between inner blocks and walls | [Refer Sec 2.2 for Details](#22-steering-selection) |
| Drive motor | Lego EV3 → TT-GM25 | Lego motor was run at 100% speed and had no headroom to increase robot speed. | [Refer Sec 2.6 for Details](#26-speed-torque-calculation-drive-motor-selection) |
| Drive motor | TT-GM25 → Pololu 4861 | TT-GM25 failed in a month. Chose Pololu motor for reliability | [Refer Sec 5.4 for Details](#541-drive-motor-burnout--tt-gm25-to-pololu-4861)|
| Pillar-avoidance steering law | Fixed vertical target line → angle-based target-line geometry|The delta between the robot and obstacle reduced as the robot approached the pillar with Fixed-line delta, forcing hacky edge-case handling| [Centroid-tracking calibration tool](src/tools/drive_straight_tune_target.py)  [Section 4.4.5](#445-pass-traffic-sign---target-line-geometry)|
| Drive speed | Fixed speed (86% / 92%) → Variable speed by obstacle distance | Fixed high speed caused repeated back-off recoveries, worsening lap time |[Details for Variable Speeds](#532-speed-vs-accuracy--why-we-moved-to-variable-speed) |
| ToF sensor init | Boot-time check only → runtime re-init → GPIO Pull-Up fix | Wall collisions in ~1-in-20 parking runs | [Details for TOF sensor Dropout](#542-tof-sensor-dropout-during-parking) |
| Wheel-gearbox alignment | Bare 3D-printed gearbox → added axle-support bracket | Wobble at the wheel showed up as jitter in the camera feed | [Details of Wheel Gearbox alignment issue](#543-wheel-wobble-showing-up-as-camera-jitter)|

---

# 6 Reproducibility & GitHub Organization

Our robot is fully reproducible and this section outlines all the details required to build the robot from scratch. It explains our git file structure, how to build the robot, how to setup the software and how to test it.

---

## 6.1 Repository Structure & Module Map

This section gives a high-level map of the Git Hub repository. It highlights the purpose of each folder and what kind of files reside in it. Each folder also has its own ReadMe which details the purpose of files within that folder.

```
greenbotics-2026-main/
├── docs/           # Engineering documentation (source .md files) and supporting diagrams/photos
├── matlab/         # MATLAB Open Challenge prototype and simulation report assets
├── models/         # 3D-printable chassis STL files and KiCad PCB project
├── schemes/        # Wiring diagram, chassis renders, mount reference images
├── src/            # Python code that runs on the Raspberry Pi 5 (open/obstacle challenge, motors, sensors, tools, etc.)
├── t-photos/       # Team photo(s)
├── test/           # Master test tracker and reference test-session track layouts
├── v-photos/       # Vehicle photos (top/bottom/front/back/left/right + base plate)
├── video/          # Link(s) to performance videos
├── README.md
└── .gitignore
```

## Folder Guide

| Folder | Short Description | README |
|---|---|---|
| `docs/` | Source engineering documents behind this README (Mobility, Power & Sense, Software, Systems Thinking, Reproducibility) plus all supporting diagrams and raw robot photos/videos. | [docs/README.md](docs/README.md) |
| `matlab/` | MATLAB Open Challenge algorithm prototype and simulation report images. | [matlab/README.md](matlab/README.md) |
| `models/` | 3D-printable chassis STL files and the KiCad PCB project (schematic + layout) for the custom PCB. | [models/README.md](models/README.md) |
| `schemes/` | Wiring diagram, chassis build-step renders, and 3D-part mount reference images. | [schemes/README.md](schemes/README.md) |
| `src/` | Python code that runs on the Raspberry Pi 5 — Open Challenge and Obstacle Challenge entry points, motor/sensor/vision hardware-abstraction modules, calibration tools, and standalone experiment scripts. | [src/README.md](src/README.md) |
| `t-photos/` | Team photo(s). | [t-photos/README.md](t-photos/README.md) |
| `test/` | Master test tracker document and reference master-session test-track layout images. | [test/README.md](test/README.md) |
| `v-photos/` | Vehicle photos — Top, Bottom, Front, Back, Left, Right, Base Plate — satisfies the "photos from every side" mandatory requirement. | [v-photos/README.md](v-photos/README.md) |
| `video/` | Link(s) to Open Challenge and Obstacle Challenge performance videos (YouTube). | [video/README.md](video/README.md) |

---

## 6.2 Robot Build Instructions

**Step 1: Print the 3D parts**

- STL files for wheel shaft, bottom chassis, camera mount, differential gear box top case, motor shaft, bumper, top chassis, servo horn and wheel bracket are in models/chassis/.  
- The print settings for Bambu Lab A1 are in models/chassis/settings/  
- If you use a different printer and cannot import above settings, follow the settings below:

**Global Slicer Settings**

* **Material:** PLA  
* **Layer Height:** 0.2mm  
* **Infill Pattern:** Gyroid  
* **Walls:** 2 Wall Loops  
* **Infill density:** 15%

**Part Overrides**

* **Camera Mount:** 25% Infill  
* **Bearing to Wheel Shaft:** 4 Wall Loops  
* **Motor Shaft:** 100% Infill | 4 Wall Loops  
* **Bumper:** TPU(Flex) | 7% Infill

3D parts list

**Step 2: Assemble the Ackerman steering**

Build the steering assembly using the Lego parts as shown in schemes/

Ackermann steering was built using Lego components and a custom 3D part for Variable Servo Horn, which was **specially designed through trial and testing** so that it may accommodate a shifting lego screw in the backside for Ackerman.

<table style="width: 100%; text-align: center; border-collapse: collapse;">
   <tr>
    <td style="padding: 10px;">
      Ackerman
    </td>
    <td style="padding: 10px;">
      AckermanAssembly
    </td>
  </tr>
</table>

**Step 3: Assemble the Robot**

- Use appropriate screws at each step to affix individual parts  
- Assemble the 3D printed parts as per Step 1 and attach Pololu 4861 motor and the Metal Differential Gear in the rear cavity  
- Insert the Ackerman steering assembly in the front cavity  
- Assemble the 3D printed parts as per Step 2 and attach EMAX servo motor  
- Assemble the 3D printed parts as per Step 3 and 4  
- Attach front and rear wheels

3D Assembly

**Step 4: Fabricate the PCB**

- Fabricate the PCB from the KiCad files in models/PCB/ using KiCad.

PCB

**Step 5: Solder the electronics with safe sequence**

- Solder all headers to the PCB.  
- Solder the power modules.
- Attach Raspberry Pi 5.  
- Attach the battery and verify the Raspberry Pi 5 boots.  
- Solder the startup switch and LED and verify with a simple test program.  
- Attach the motor driver module and verify motor control with a test program.  
- Attach the sensor modules and verify sensor readings with a test program.  
- Attach the IMU module and verify orientation readings with a test program.  
- Attach the Raspberry Pi 5 wide-angle camera.

Soldered Parts on PCB

**Step 6: Install the software**

- See [Software Setup](#63-software-setup--running-the-robot) below for detailed steps on setting up software

**Step 7: Verify robot runs\!**

- Run the robot as per steps in [Testing Workflow](#64-testing-workflow) and it will run smoothly\!  
- If the rear wheel shaft doesn’t move smoothly with your hands, apply grease to the gear teeth using the greasing hole underside the robot chassis.

---

## 6.3 Software Setup & Running the Robot

### 6.3.1 Flash and configure Raspberry Pi OS

- Install Raspberry Pi OS (Trixie, 64-bit) on the Raspberry Pi 5.
- Connect to Wi-Fi and confirm internet access, then update the system:
```bash
sudo apt update
sudo apt upgrade
```

### 6.3.2 Install Git and clone Greenbotics Repo

```bash
sudo apt install -y git
git clone https://github.com/Devansh-awat/greenbotics-2026.git
cd greenbotics-2026
```

### 6.3.3 Install system-level dependencies

```bash
sudo apt install -y python3-pip python3-gpiozero python3-lgpio \
  python3-picamera2 python3-numpy python3-opencv python3-tk  \
  python3-pil.imagetk python3-libcamera i2c-tools libi2c-dev python3-dev
```

### 6.3.4 Install Python dependencies

```bash
pip3 install --break-system-packages -r src/requirements.txt
```

### 6.3.5 Enable I2C bus & PWM

Enable I2C bus using following command
```
sudo raspi-config nonint do_i2c 0 
```

Enable PWM, i2c-2 and configure pull ups by adding the below at the end of `/boot/firmware/confxtig.txt` using `nano`

```
dtparam=i2c_arm=on
dtparam=i2c_arm_baudrate=100000
dtoverlay=i2c3-pi5,pins_14_15
gpio=4,5,14,15=pu
dtoverlay=pwm-2chan
gpio=23=pu
```
Then `sudo reboot`

### 6.3.6 Run the code

```bash
cd /path/to/greenbotics-2026

# Open Challenge
python3 -m src.open_challenge.main

# Obstacle Challenge
python3 -m src.obstacle_challenge.main
```

---

## 6.4 Testing Workflow 
Having built the robot using [Section 6.2](#62-robot-build-instructions) and [Section 6.3](#63-software-setup--running-the-robot) above, follow below instructions to test it on the field.

**Open Challenge test procedure**
1. Place robot in the starting section on a WRO FE mat with its walls.
2. Run `python3 -m src.open_challenge.main`.
3. Confirm: 3 laps completed, correct direction, no wall contact, stop in finish section.

**Obstacle Challenge test procedure**
1. Place traffic signs (red/green) in a valid randomized configuration.
2. Run `python3 -m src.obstacle_challenge.main`.
3. Confirm: correct avoidance (red = pass left, green = pass right), no pillar contact, 3 laps completed, parking attempted.

---

## 6.5 Parts List (Bill of Materials)

This is a consolidated list of every major component used to build the robot, as described across the Mobility, Power & Sensor, and Reproducibility sections of this document.

| Category | Component 
|---|---|
| Compute | Raspberry Pi 5 |
| Drive Motor | Pololu 4861 (25D metal gearmotor, 12V, 1800 RPM, with Encoder) |
| Steering Motor | EMAX ES08A II servo |
| Differential | Metal differential gear, 38:13 ratio |
| Wheels | Lego SPIKE Prime medium wheels, 56mm |
| Chassis & Structural Parts | Custom 3D-printed parts (PLA) |
| Steering Linkage | Lego Ackermann assembly + Variable Servo Horn |
| Battery | 11.1V 1500mAh LiPo |
| Voltage Regulator | 25W step-down converter (12V → 5.2V) |
| Motor Driver | TB6612FNG |
| Custom PCB | Greenbotics designed PCB |
| Camera | Raspberry Pi Camera Module 3 Wide |
| Distance Sensor | VL53L4CD ToF sensor ×4 |
| IMU | BNO086 |
| Battery Monitor | Voltmeter |
| Wiring/Connectors | Wiring harness + PCB headers |

---

## 6.6 Engineering Journal

The Engineering Journal is a printer friendly PDF export of the soft copy version of this README.md. You can find it in [docs/Engineering_Journal](docs/Engineering_Journal/Engineering_Journal.pdf)`

---

## 6.7 Matlab Journal

The Matlab code and journal is in the [matlab folder](matlab/) of this repository. 

---

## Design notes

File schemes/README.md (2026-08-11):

This directory contains the following schematic diagrams

- Wiring diagrams
- 3D printed parts diagrams
- Chassis assembly steps diagrams

</br>

- Circuit Diagram

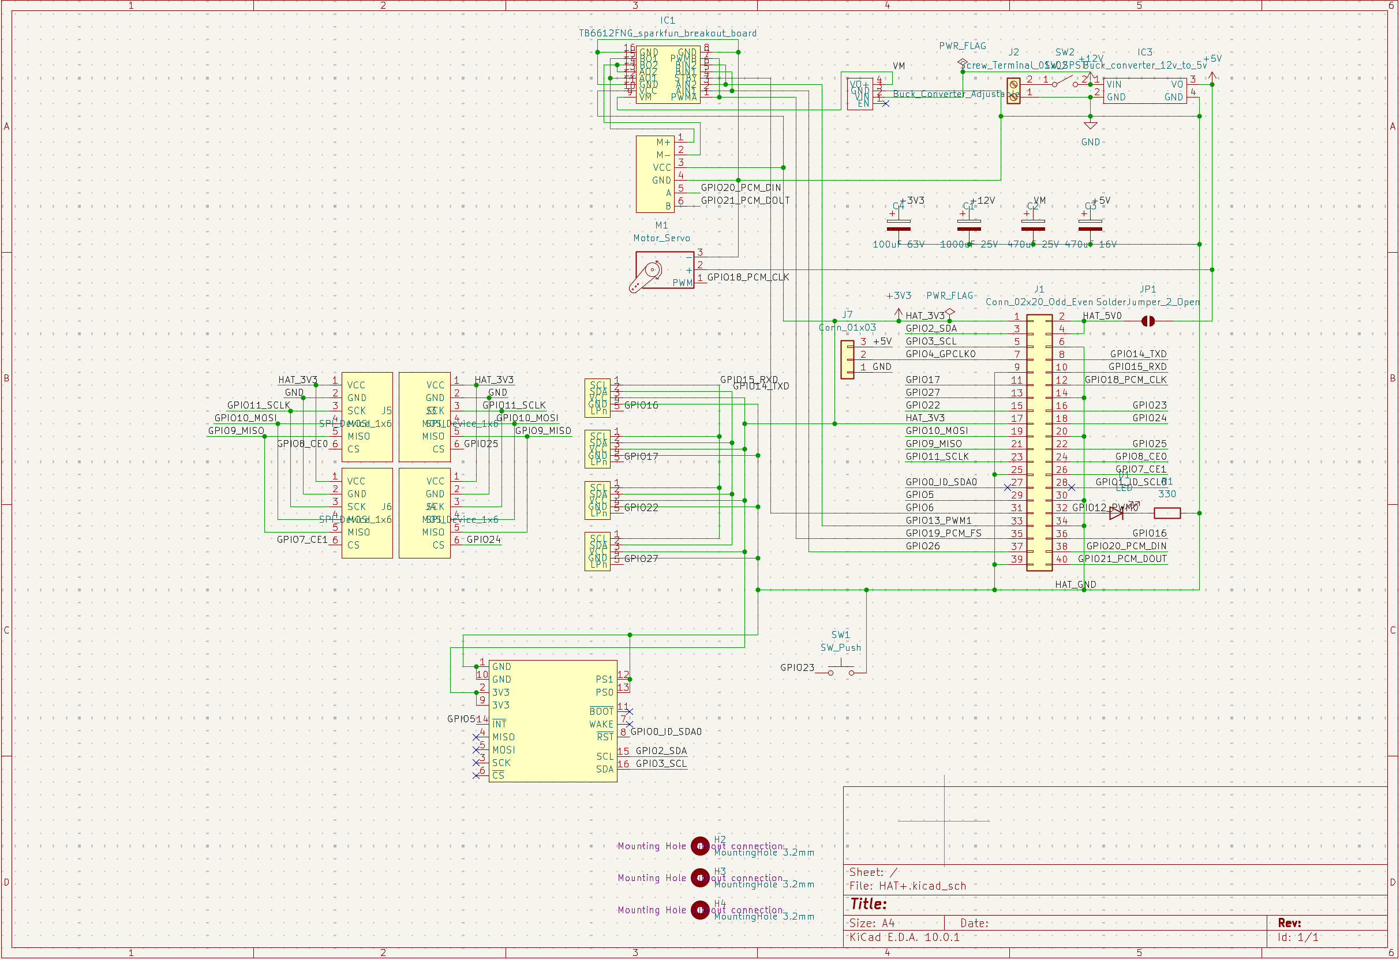
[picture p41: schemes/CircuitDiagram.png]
CircuitDiagram


- Bearing to wheel shaft

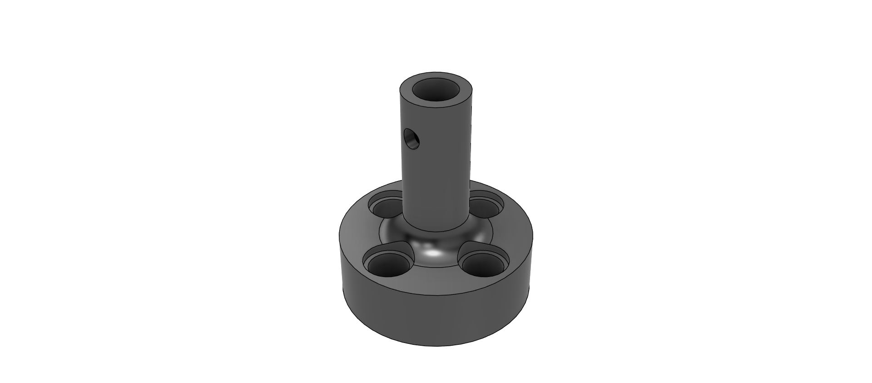
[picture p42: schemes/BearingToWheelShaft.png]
BearingToWheelShaft

 
- Bottom chasis

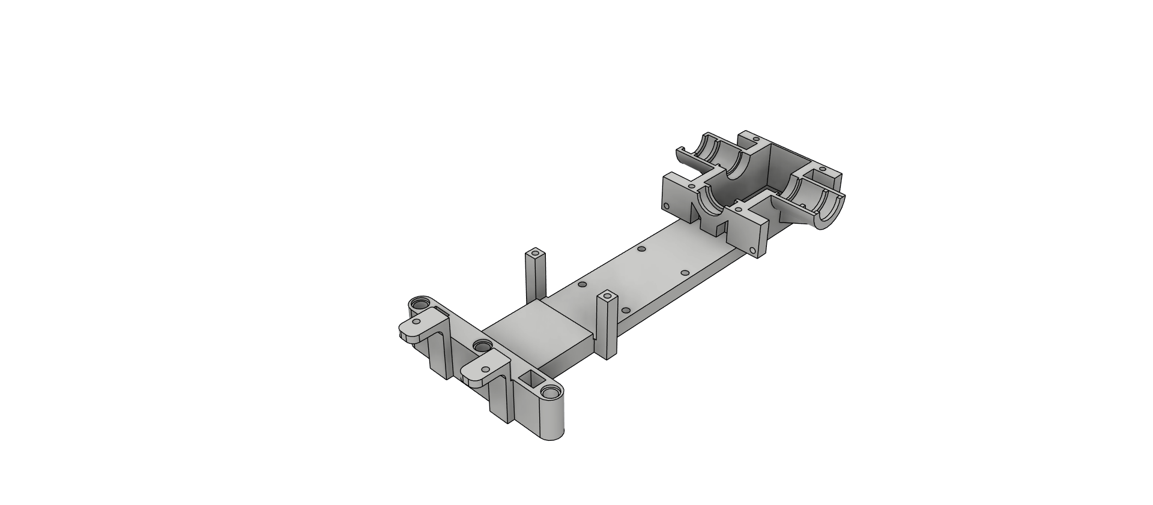
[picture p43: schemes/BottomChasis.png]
BottomChasis

 
- Camera mount

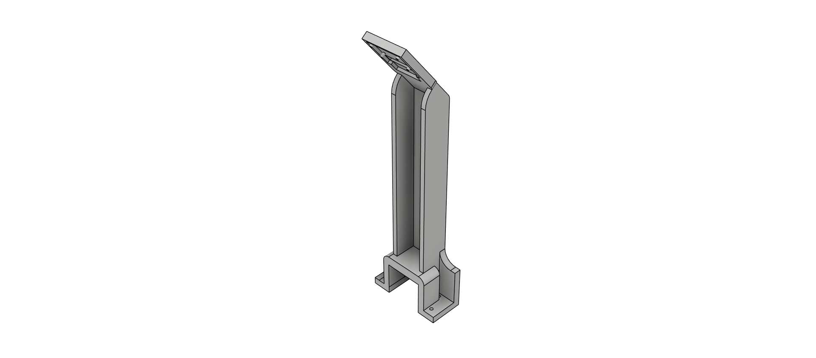
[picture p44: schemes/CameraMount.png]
CameraMount


- Diiferential Mount Top

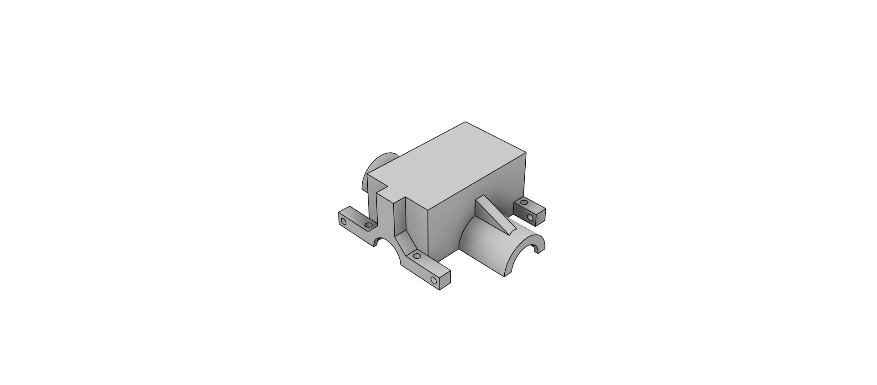
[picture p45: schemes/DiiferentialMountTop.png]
DiiferentialMountTop


- Motor Shaft

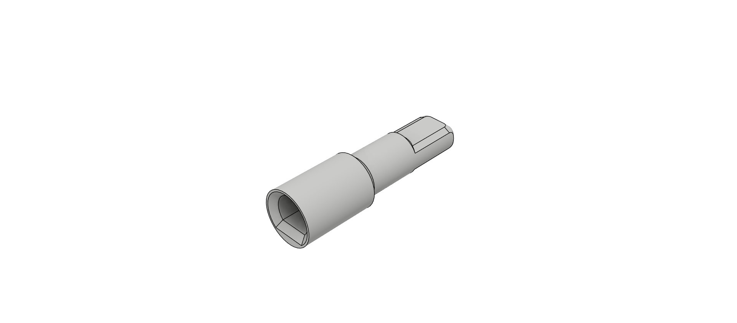
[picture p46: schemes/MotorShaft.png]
MotorShaft


- Servo Mount

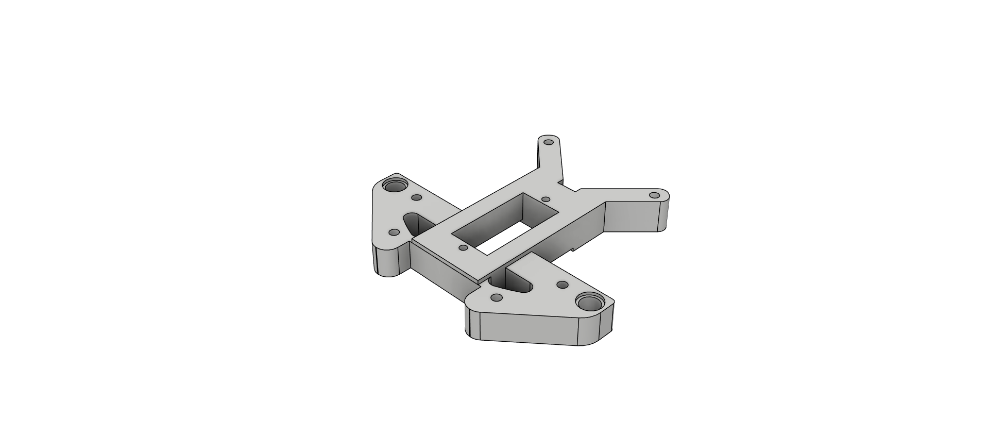
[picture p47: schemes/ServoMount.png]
ServoMount


- Top Chasis

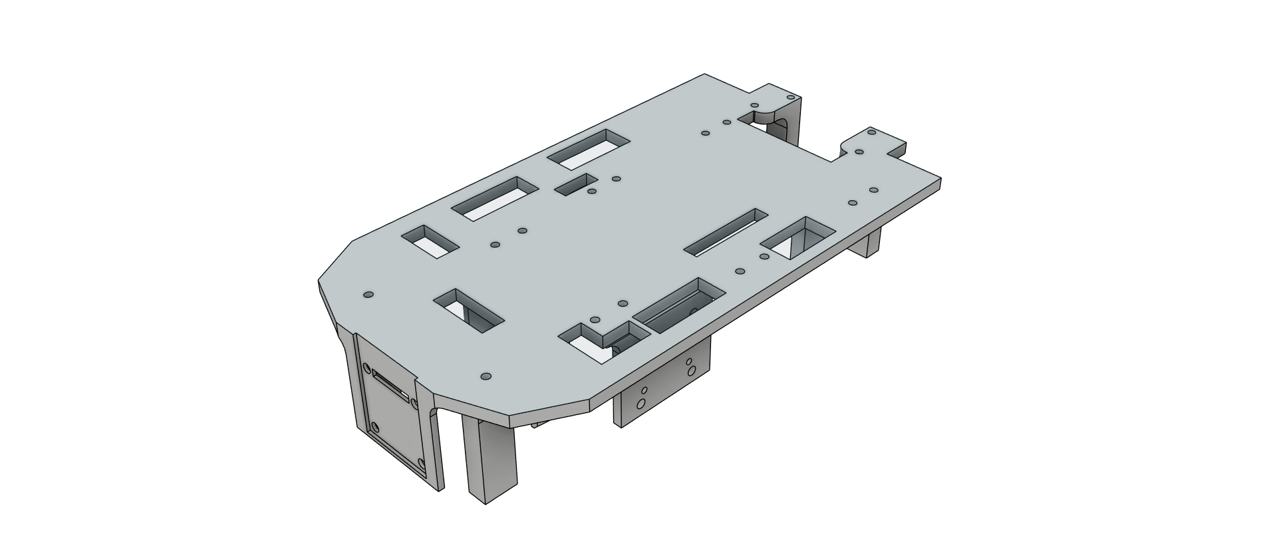
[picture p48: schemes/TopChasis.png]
TopChasis


- TPU Bumper

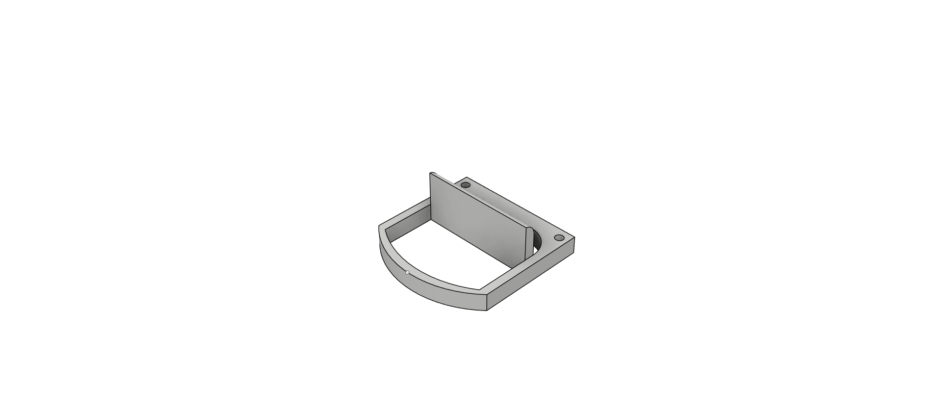
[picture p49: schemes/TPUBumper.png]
TPUBumper


- Variable ServoHorn

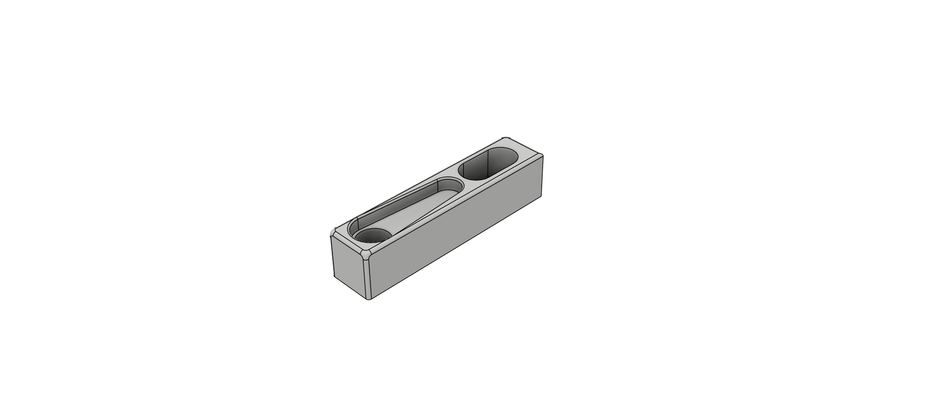
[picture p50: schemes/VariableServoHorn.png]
VariableServoHorn


- Wheel Stabilizer

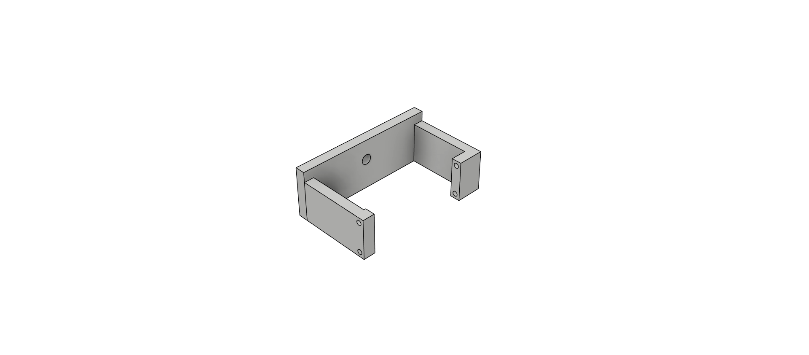
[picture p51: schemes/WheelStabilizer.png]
WheelStabilizer


- Ackerman

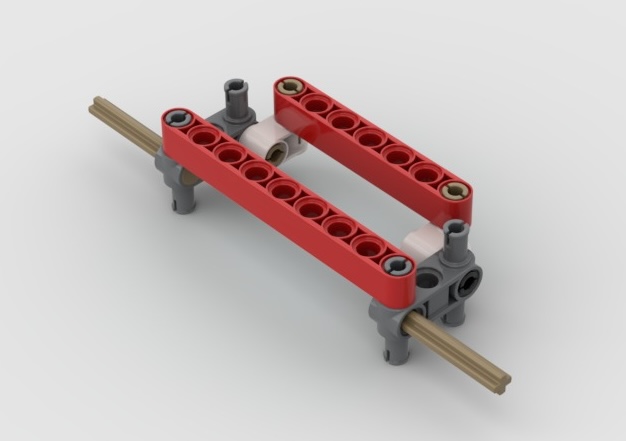
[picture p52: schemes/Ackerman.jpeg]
Ackerman


- Ackerman Assembly

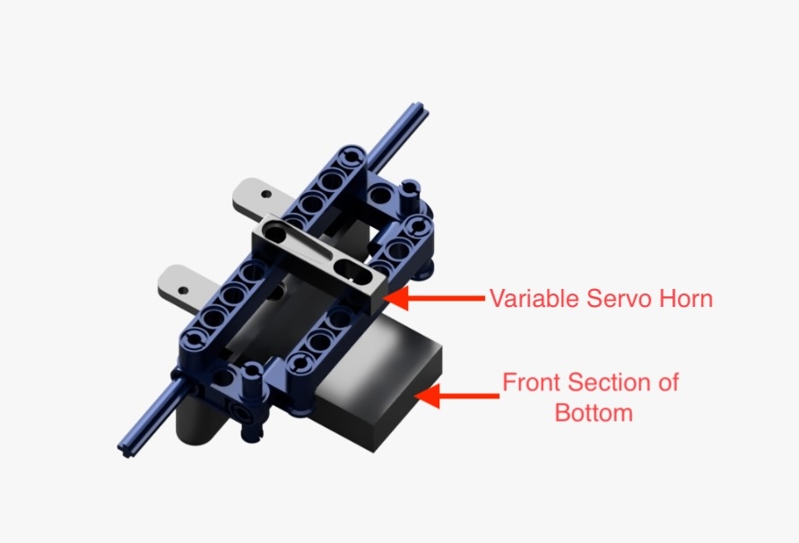
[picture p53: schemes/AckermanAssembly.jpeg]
AckermanAssembly


- Chassis step 1

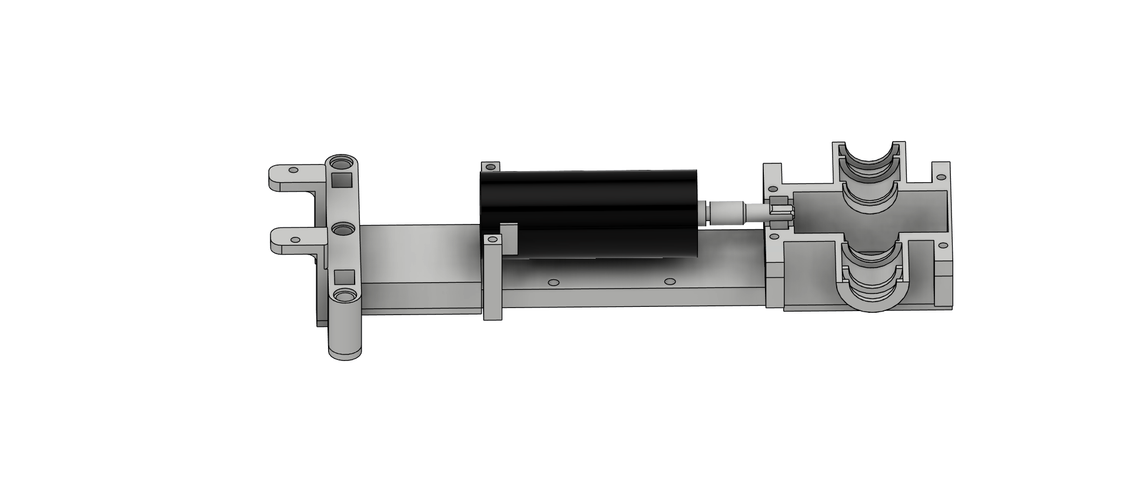
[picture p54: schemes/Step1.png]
Chassis_Step1


- Chassis step 2

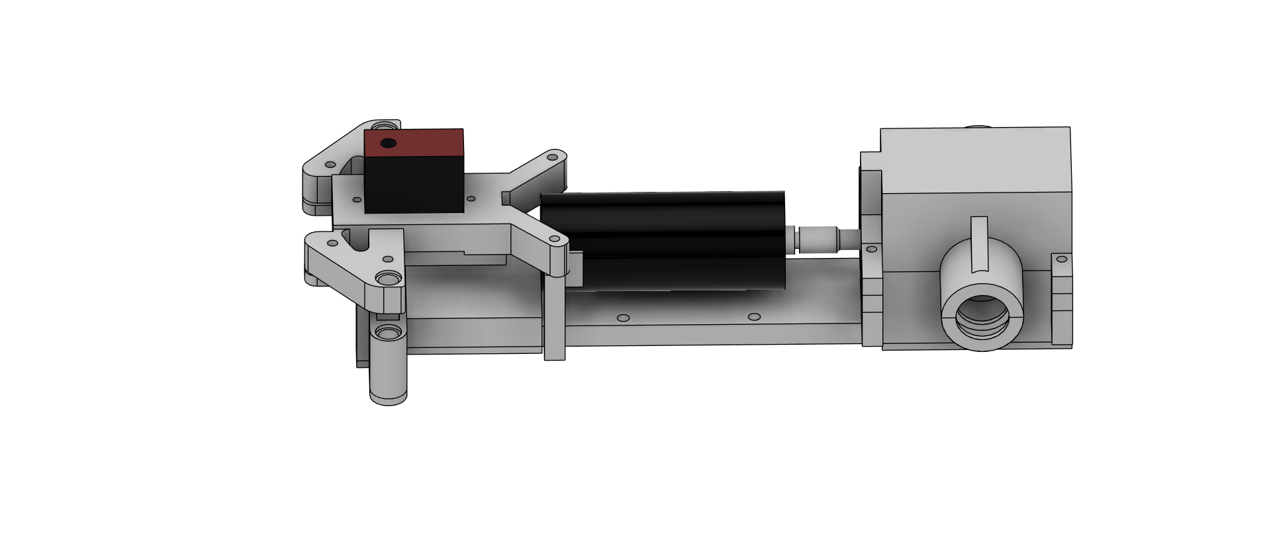
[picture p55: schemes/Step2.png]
Chassis_Step2


- Chassis step 3

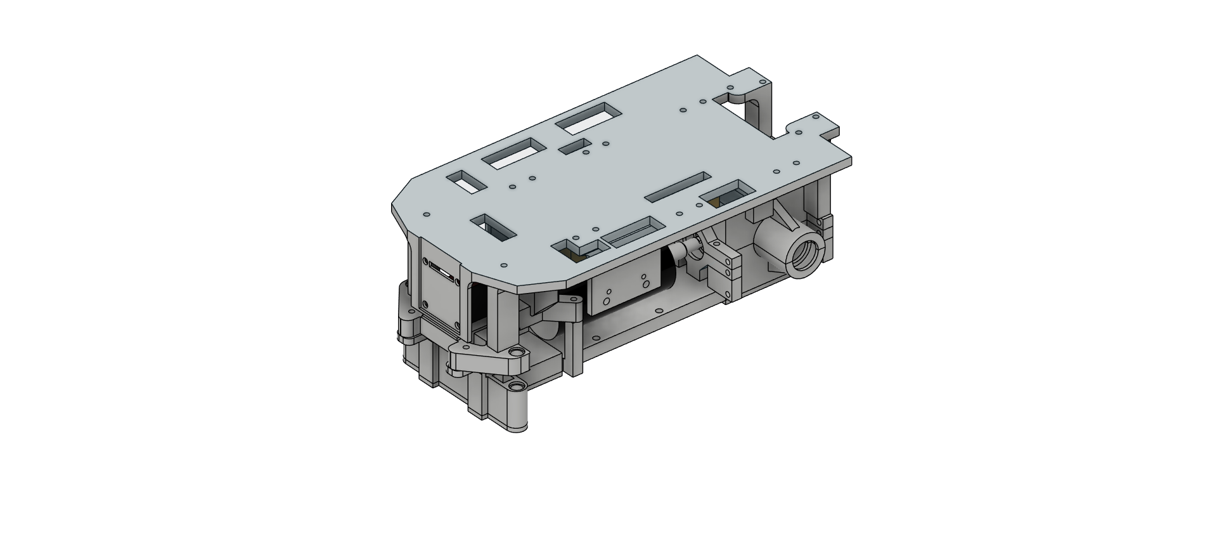
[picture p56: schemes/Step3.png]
Chassis_Step3


- Chassis step 4 (final)

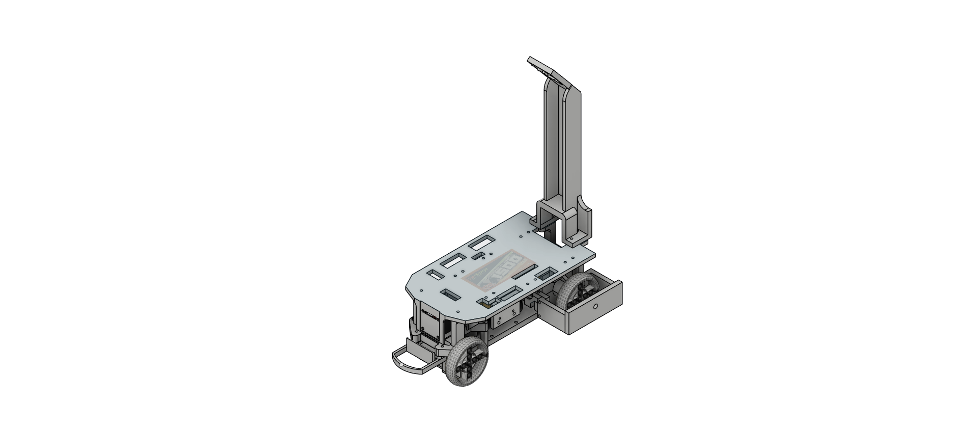
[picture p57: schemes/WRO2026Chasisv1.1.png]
Chassis_Step4


---

## Files in this folder

| File | Description |
|---|---|
| `CircuitDiagram.png` | Full circuit diagram — power and signal connections between battery, converters, RPi 5, motor driver, servo, camera, IMU, and ToF sensors. |
| `BearingToWheelShaft.png` | Bearing-to-wheel-shaft part render. |
| `BottomChasis.png` | Bottom chassis part render. |
| `CameraMount.png` | Camera mount part render. |
| `DiiferentialMountTop.png` | Differential mount (top) part render. |
| `MotorShaft.png` | Motor shaft part render. |
| `ServoMount.png` | Servo mount part render. |
| `TopChasis.png` | Top chassis part render. |
| `TPUBumper.png` | TPU bumper part render. |
| `VariableServoHorn.png` | Variable servo horn part render. |
| `WheelStabilizer.png` | Wheel stabilizer part render. |
| `Step1.png` | Chassis build step 1. |
| `Step2.png` | Chassis build step 2. |
| `Step3.png` | Chassis build step 3. |
| `WRO2026Chasisv1.1.png` | Chassis build step 4 (final) — current chassis version reference image. |

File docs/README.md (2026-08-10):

# Documentation (`docs/`)

This folder holds the supporting diagrams referenced throughout the main [README](../README.md). It contains a single `diagrams/` subfolder, organized by subsystem, holding PNG/JPG/GIF images and their `.drawio` source files.

## Folder Purpose Map

| Path | Contents | Referenced from (main README section) |
|---|---|---|
| `diagrams/mobility/` | PNG/JPEG diagrams and photos for drivetrain, steering, differential, and speed/torque calculations. | Section 1 — Mobility & Mechanical Design |
| `diagrams/powerNsense/` | PNG/JPEG diagrams and photos for power architecture, wiring, circuit, and sensor placement/calibration. Includes `.drawio` source files alongside their exported `.png`. | Section 2 — Power & Sensor Architecture |
| `diagrams/software/` | PNG diagrams for software architecture, state machine, and control loops, with `.drawio` sources. Its `pipeline/` sub-subfolder holds vision-pipeline stage screenshots (raw frame → HSV → masks → annotated output). | Section 3 — Software Architecture & Obstacle Strategy |
| `diagrams/systemsThinking/` | PNG/JPEG/GIF diagrams and photographic evidence for system integration and failure-analysis case studies. | Section 4 — Systems Thinking & Engineering Decisions |

Each subfolder is a flat collection of images (and, where applicable, their `.drawio` source) for that subsystem.

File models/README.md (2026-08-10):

# Models (`models/`)

This folder holds the CAD/PCB source files for the robot's 3D-printed chassis parts and the custom PCB.

## Nested folders (contents summarized here per project convention — no separate README inside)

**`chassis/`** — 3D-printable STL files for the chassis:
- `BearingToWheelShaft.stl`
- `BottomChasis.stl`
- `CameraMount.stl`
- `DifferentialMountTop.stl`
- `MotorShaft.stl`
- `ServoMount.stl`
- `TopChasis.stl`
- `TPUBumper.stl`
- `VariableServoHorn.stl`
- `WheelStabilizer.stl`

**`PCB/`** — KiCad project for the custom PCB (single, current design — `HAT+`):
- `HAT+.kicad_pcb` — PCB layout
- `HAT+.kicad_sch` — schematic
- `HAT+.kicad_pro` — project file
- `HAT+.kicad_prl` — project local settings
- `HAT+.kicad_dru` — design rules
- `HAT_Plus_sch.kicad_sch` — schematic (supporting sheet)
- `fp-lib-table`, `fp-info-cache` — footprint library references/cache
- `sym-lib-table` — symbol library reference

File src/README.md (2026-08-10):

# Software Code Walkthrough (`src`)

This is a code walkthrough for the Python code that runs on the Raspberry Pi 5. It covers hardware interfaces, program flow, and core algorithm logic.

See the main [Main Readme - 5.3](../README.md#53-software-setup--running-the-robot) for install steps and detailed design aspects in main [ - 3](Main Readme../README.md#3-software-architecture--obstacle-strategy)

## 1. Hardware Interfaces

Each hardware component has its own driver module. All of them talk to RP1 (GPIO, PWM, I2C, SPI) directly, so the robot needs no separate microcontroller.

**Servo steering** (`motors/servo.py`) uses hardware PWM via RP1. Every angle gets clamped to safe limits before it reaches the servo:

```python
servo_pwm = HardwarePWM(pwm_channel=config.SERVO_PWM_CHANNEL,
                         hz=config.SERVO_PWM_FREQ, chip=config.SERVO_PWM_CHIP)

def set_angle(input_angle: float):
    adjusted_angle = input_angle + config.SERVO_CENTER_OFFSET
    clamped_input = max(config.INPUT_ANGLE_MIN_SERVO,
                         min(config.INPUT_ANGLE_MAX_SERVO, adjusted_angle))
    # ...maps clamped_input to the calibrated PWM output range
```

**Drive motor** (`motors/motor.py`) uses hardware PWM for speed and GPIO pins for direction. The wheel encoder reads through RP1's PIO block:

```python
motor_pwm = HardwarePWM(pwm_channel=config.MOTOR_PWM_CHANNEL,
                         hz=config.MOTOR_PWM_FREQ, chip=config.MOTOR_PWM_CHIP)
encoder = IncrementalEncoder(board.D20)   # PIO-backed, counts pulses in hardware

def _set_speed(speed):
    motor_pwm.change_duty_cycle(max(0, min(100, speed)))
```

**Distance sensors** (`sensors/distance.py`) bring up 4 VL53L4CD sensors one at a time on the same I2C bus. Each sensor's XSHUT pin holds it in reset until its turn, so every sensor gets a unique address:

```python
for channel in SENSOR_CHANNELS:
    _xshut_devices[channel] = DigitalOutputDevice(channel, initial_value=False)  # hold all low
# then _bring_up() releases one XSHUT at a time and re-addresses that sensor
```

**Encoder PIO program** (`sensors/encoder.py`) loads a small assembly program onto RP1 that counts quadrature pulses in hardware. This keeps every pulse count accurate no matter how busy the CPU gets — see [Main Readme 3.7.1](../README.md#371-why-pio-for-the-encoder) for the full explanation.

## 2. Program Flow

Both challenges run a sense → decide → act loop. The main README has the flowcharts for this:
- Open Challenge flow: [Main Readme 3.3, Open Challenge section](../README.md#33-open-challenge--srcopen_challengemainpy)
- Obstacle Challenge state machine: [Main Readme 3.4 , Obstacle Challenge section](../README.md#34-obstacle-challenge--state-machine--algorithms)
- Threading model: [Main Readme 3.2.1 , System Architecture](../README.md#321-threading-model)

Here are some important code snippets explaining the core algorithms we have used: 

**Priority state machine** runs fresh every frame inside the main loop, and the highest priority match wins. The main README has the full state table in [Main Readme 3.4.1](../README.md#341-states--priority-order):

```python
if close_black_area > 3000:
    # P1: AVOID HEADON — hard steer away from wall dead ahead
elif detected_blocks:
    # P2: PASS TRAFFIC SIGN — target-line geometry steers around pillar
elif wall_inner_left < 100 or wall_inner_right < 100:
    # P3: CORNER TURN — amplify remaining wall area to force the turn
else:
    # P4: WALL FOLLOW — PD controller keeps robot centered
```

**Target-line steering** passes a pillar on the correct side using an angle-based law, tuned separately for red and green:

```python
current_angle = math.atan2(block_x - origin_x, origin_y - block_y)
steering_angle = (current_angle - IDEAL_ANGLE) * Kp
# IDEAL_ANGLE = +42.5° for red, -40.5° for green ; Kp = 1.5
```

**Gyro steering** (`steer_with_gyro`) holds a straight line or executes precise turns during parking:

```python
def steer_with_gyro(current_heading, target_heading, Kp=0.85):
    heading_error = get_angular_difference(target_heading, current_heading)
    return heading_error * Kp
```

**Turn counting** uses a debounced rising-edge check on the orange line detector, so one line crossing at high speed only counts once:

```python
orange_detection_history.append(orange_detected_this_frame)   # last 4 frames
if not orange_detection_history[-4] and all(list(orange_detection_history)[1:]):
    turn_counter += 1
    cooldown_frames = ORANGE_COOLDOWN_FRAMES   # 50-frame cooldown
```

[Main Readme 3.4.8](../README.md#348-parking-algorithm) covers the parking sequence, edge cases, and parameter tuning in full detail.

---

## Files in this folder
This is a high-level map of how files are organized within src folder.

```
src/
├── experiments/          # Standalone data-collection scripts for tuning/characterizing robot behavior
├── logs/                 # Logging setup/configuration for run logs
├── motors/               # Drive motor and steering servo control (PWM, RPM closed-loop)
├── obstacle_challenge/   # Obstacle Challenge entry point, config, and decision/control logic (includes a legacy/ subfolder of prior versions)
├── open_challenge/       # Open Challenge entry point and config
├── sensors/              # Hardware-abstraction drivers for camera, IMU, distance sensors, and encoder (includes a legacy/ subfolder of superseded drivers)
├── threads/              # Background hardware-sensor thread management
├── tools/                # Calibration and diagnostic utilities (HSV tuning, capture pipelines, sensor tests)
├── vision/               # Shared frame-processing pipeline and worker pool
└── __init__.py           # Marks src/ as a Python package (empty)
```

This is a high-level map

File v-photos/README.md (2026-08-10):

Vehicle's photos
====

This directory contains 7 photos of the vehicle

Top
Top

Bottom
Bottom

Front
Front

Back
Back

Left
Left

Right
Right

Base Plate
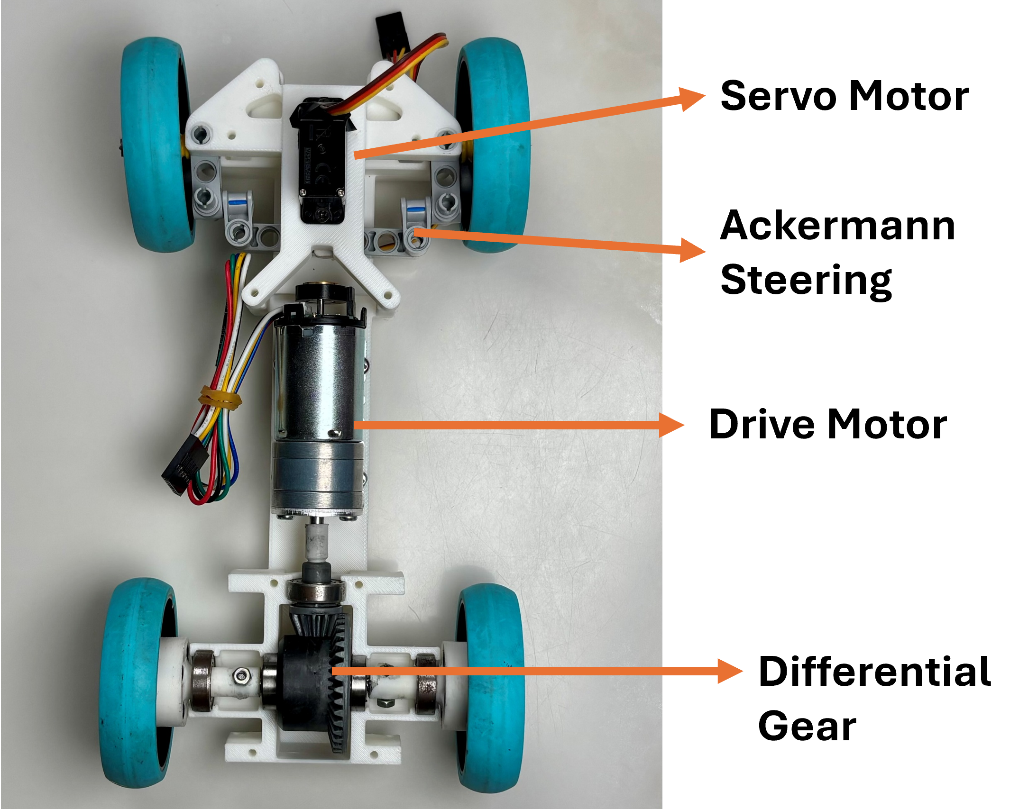
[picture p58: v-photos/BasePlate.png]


---

## Files in this folder

| File | Description |
|---|---|
| `Top.png` | Vehicle top view. |
| `Bottom.png` | Vehicle bottom view. |
| `Front.png` | Vehicle front view. |
| `Back.png` | Vehicle back view. |
| `Left.png` | Vehicle left view. |
| `Right.png` | Vehicle right view. |
| `BasePlate.png` | Base plate component layout photo (referenced in main README Section 1.9, Assembly photos). |

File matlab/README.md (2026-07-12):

# MATLAB Simulation Report — Obstacle Challenge Digital Twin

## Table of Contents
- [Problem Statement](#problem-statement)
- [Project Objectives](#project-objectives)
- [Simulation Architecture](#simulation-architecture)
- [Perception: Running Our Real Vision Code](#perception-running-our-real-vision-code)
- [Navigation and State Machine](#navigation-and-state-machine)
- [Official WRO Randomization](#official-wro-randomization)
- [Full Mission: Parking and Both Directions](#full-mission-parking-and-both-directions)
- [Engineering Iterations](#engineering-iterations)
- [Validation Results](#validation-results)
- [Power Budget: Prediction → Measurement → Verification](#power-budget-prediction--measurement--verification)
- [Closing the Loop: Simulation-Tuned Parameters](#closing-the-loop-simulation-tuned-parameters)
- [How to Run](#how-to-run)
- [Known Limitations](#known-limitations)
- [Conclusion](#conclusion)

---

## Problem Statement

Testing robot navigation on the physical WRO arena is slow, unrepeatable, and
risky. The Obstacle Challenge randomizes the traffic-sign layout **before every
round** (coin tosses + 36 official cards), so a strategy that works on one
layout can fail on the next — and physically rebuilding dozens of layouts to
test one code change is impractical. Every crash also risks the steering servo
and camera mount.

Our answer is a MATLAB **digital twin**: a simulated arena where our robot's
actual perception strategy runs in closed loop — perception → decision →
actuation → physics → perception — every test layout is generated by the
official randomization procedure, and performance is measured in numbers
instead of impressions. Unlike a scripted visualization, a closed-loop twin
can *fail*, and it fails exactly where our algorithm is weak: that is the
point of simulating.

## Project Objectives

1. Reproduce the field to official dimensions: 3×3 m mat, 1×1 m centre box,
   sign seats at the exact card positions (rows 400/600 mm from the outer wall).
2. Run our robot's **real vision strategy** (HSV block detection + proportional
   centroid steering from `src/obstacle_challenge/`) against a simulated camera.
3. Generate every test layout with the **official randomization procedure**.
4. Complete the full mission — **3 laps + parallel parking** — in both driving
   directions, without touching walls, signs, or parking barriers.
5. Measure everything and validate statistically over batches of layouts.

## Simulation Architecture

One shared control step is used by both the interactive simulator and the
headless batch evaluator, so the two can never drift apart.

| Module | Role | Real-robot counterpart |
|---|---|---|
| `run.m` | Interactive sim: live map, simulated camera, telemetry, Randomize button | debug UI |
| `control_step.m` | One 30 Hz perception + decision + physics step | main control loop |
| `render_frame.m` | Simulated 640×360 camera: walls, pillars, magenta barriers | Picamera2 |
| `find_biggest_block.m` | ROI crop → HSV masks → largest portrait blob | camera module |
| `ray_wall_distance.m` | Ray-cast wall distances | VL53 ToF sensors |
| `place_obstacles_random.m` | Official coin + 36-card randomization | judges' procedure |
| `parking_control.m` | Post-lap-3 parking maneuver | parking routine |
| `simulate_run.m` / `evaluate.m` | Headless runs / batch statistics | test harness |
| `sweep_kp.m` | Steering-gain sweep on paired layouts | tunes `config.py` |
| `power_budget.m` | Electrical model: rails, battery, runtime | battery/regulator selection |

## Perception: Running Our Real Vision Code

The simulated pipeline ports the robot's code line by line: the same 640×360
frame size, the same ROI crop, the same HSV thresholds (red split across the
hue wrap, 0–10 and 170–180), the same portrait filter (`height > width`) that
rejects reflections, and the same steering law:

```
servo = clamp( KP_BLOCK × (cx − target_x), ±45° )
red   → target_x = 20   (pass on its right)
green → target_x = 620  (pass on its left)
```

Because the detection path is shared with the robot's logic, an HSV threshold
that fails in simulation fails on the robot for the same reason.

## Navigation and State Machine

We evaluated two architectures and kept the one that survived testing:

- **Layered overrides (rejected):** track steering + wall repulsion + block
  avoidance added as separate corrections. Near a wall the corrections
  cancelled to zero and the robot deadlocked — observed repeatedly.
- **Unified vector field (final):** every influence is a direction vector and
  steering follows the summed direction. The lane-flow component always points
  along the track, so the resultant is never zero: the robot always has
  somewhere to go.

Block avoidance pulls toward a **pass point** 0.30 m beside each pillar,
anchored to the lane direction at the pillar (world frame). Our first version
anchored it to the robot's heading — the push direction rotated with the
robot and it orbited pillars in circles. World-frame anchoring made orbiting
geometrically impossible.

States: `DRIVING_STRAIGHT → AVOIDING_BLOCK → CLEARING → (back)`, with
`EMERGENCY_REVERSE` as a guarded last resort and a stuck watchdog (< 6 cm of
motion in 3 s forces a back-off) as the final safety net.

## Official WRO Randomization

`place_obstacles_random.m` implements the rulebook procedure, cross-checked
against the official randomization app: one coin-chosen section receives a
single sign at X2; the other three sections draw cards (never two signs on one
radius, X seats only as singles); at least one mixed-colour same-row pair is
guaranteed; seats in front of the start zone are excluded; the parking section
allows only inner-row seats. Every simulated round is a legal competition
layout — including the worst ones.

## Full Mission: Parking and Both Directions

- **Parking lot to rule:** two magenta barriers (200×20×100 mm) against the
  outer wall of the start section, gap = 1.5 × robot length. The barriers are
  solid physics objects, rendered by the simulated camera in magenta (outside
  the red/green HSV masks, so detection is unaffected), and **every touch is
  counted** — rule 9.24.7 ends a real round on contact.
- **Maneuver after lap 3:** approach → align on the lot → turn in → enter →
  straighten parallel. The verdict mirrors scoring: *full* (projection fully
  between the barriers + parallel + zero touches) or *partial*.
- **Both driving directions:** each round randomizes CW/CCW like the real
  competition; the start zone mirrors and the lot moves to the opposite half
  of the section.

## Engineering Iterations

Every design change was driven by an observed failure:

| # | Observed failure | Root cause | Fix |
|---|---|---|---|
| 1 | Endless left/right oscillation | Avoidance target ±180° from heading flipped the error sign every frame | Heading-relative targets; later replaced by vector field |
| 2 | Robot pinned against wall | Steering corrections cancelled to zero | Re-architecture: unified vector field |
| 3 | ~10 reverse cycles per sign | Reverse trigger too eager + avoidance turned back into the block's lane | Narrower trigger + cooldown + decaying push while clearing |
| 4 | Loop-the-loop circles at pillars | Heading-relative push rotates with the robot (orbit feedback) | World-frame pass points |
| 5 | Wedged between sign and outer wall | Wall repulsion covered the whole legal corridor | Repulsion range cut to 0.22 m |
| 6 | Run wasted at spawn | Randomizer ignored start-zone seat rules | Official forbidden-seat rule implemented |
| 7 | Simulation lag | Full-frame temporaries, 30 Hz HSV, console spam | Cached buffers, 10 Hz half-res vision — 23× real time |
| 8 | 55 barrier touches while parking | Diagonal reverse entry grazed the barriers | Align-then-enter maneuver: zero touches by construction |

## Validation Results

**12 officially randomized layouts, random directions, reproducible (seed 42):**

```
RESULT: 12 / 12 missions complete (3 laps + parked)   (100%)
Full parallel parks (15 pts): 12 / 12    Barrier touches: 0 total
Avg mission time: 148.2 s    (5 CW rounds, 7 CCW rounds)
Worst clearance to any sign: 0.14 m — no sign moved, ever
```

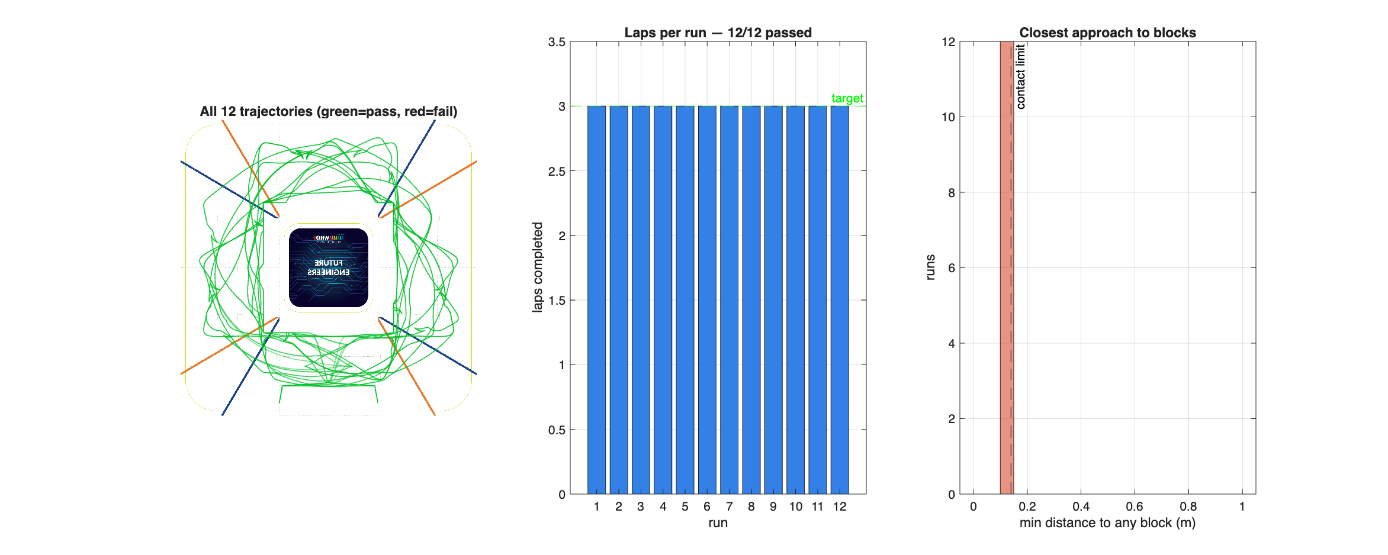
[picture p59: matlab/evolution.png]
Batch evaluation


Per-run reports (trajectory coloured by state, speed profile, clearance-vs-time,
summary statistics) are saved automatically after every run.

## Power Budget: Prediction → Measurement → Verification

1. **Prediction.** With datasheet estimates, `power_budget.m` flagged a
   brownout risk: the Pi and a stalling steering servo could overload a
   generic 3 A regulator exactly when the robot fights an obstacle.
2. **Measurement.** We measured the actual vehicle: our regulator is an
   XY-3606 rated 5 A, the Pi draws 5.7 W under full vision processing (PMIC
   readings, no throttling), the servo stalls at ~0.8 A, and whole-robot
   battery current is 0.40 A idle / 0.80 A driving.
3. **Verification.** Peak 5 V demand is 2.3 A against the 5 A module —
   brownout ruled out with 2.2× headroom, and ~102 min runtime on our
   1500 mAh 3S pack. The model matches the multimeter within 10% at cruise,
   which is what lets us trust its answer for the one case we cannot safely
   measure: worst-case stall (44 W, 2.6 C — inside every rating).

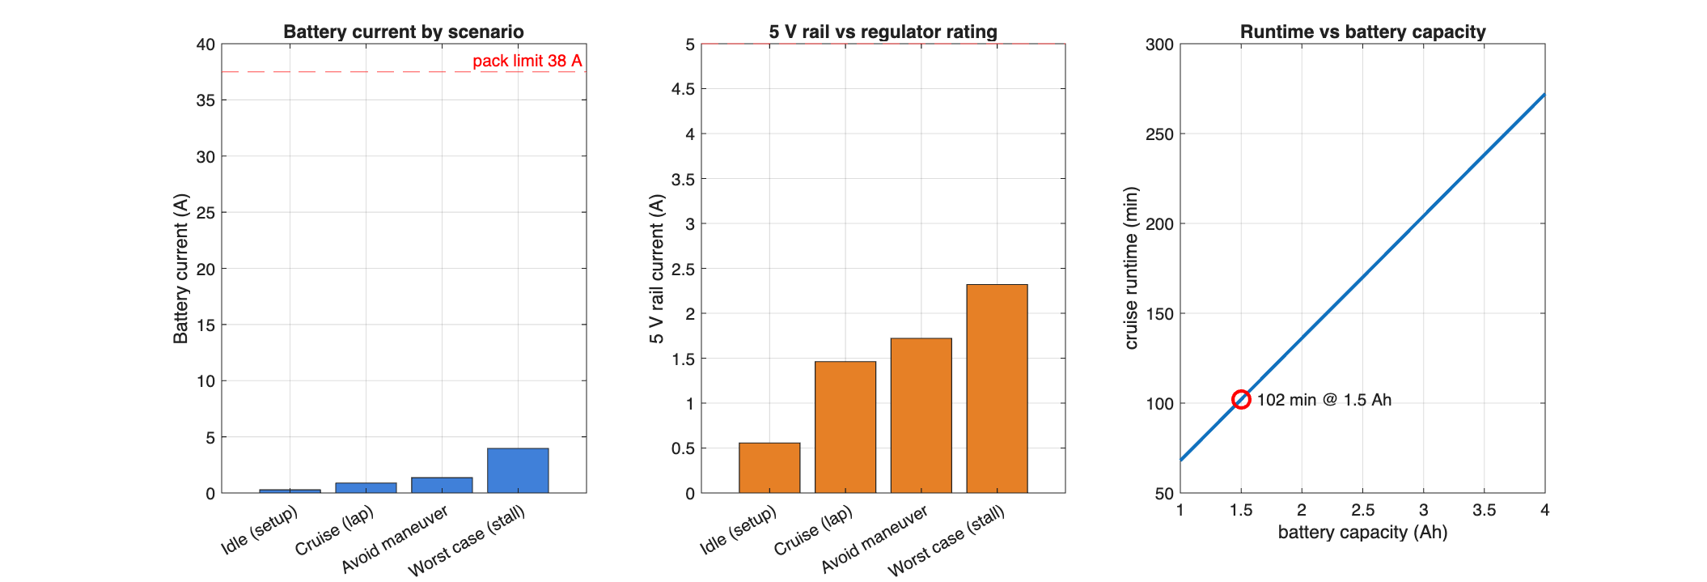
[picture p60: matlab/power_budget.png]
Power budget


## Closing the Loop: Simulation-Tuned Parameters

`sweep_kp.m` swept our camera steering gain across the **same six randomized
layouts per value** (paired seeds, so differences come from the gain, not the
layouts):

| KP_BLOCK | Pass rate | Avg mission time |
|---|---|---|
| 0.05 | 6/6 | 131.4 s |
| 0.07 | 6/6 | **129.7 s** |
| **0.09 (deployed)** | 6/6 | 132.6 s |
| 0.12 | 6/6 | 140.3 s |
| 0.15 | 6/6 | 159.5 s |

Our deployed 0.09 sits in the flat optimum; gains ≥ 0.12 cost up to +20%
mission time through oversteer. The physical tuning session can skip the
high-gain region entirely.

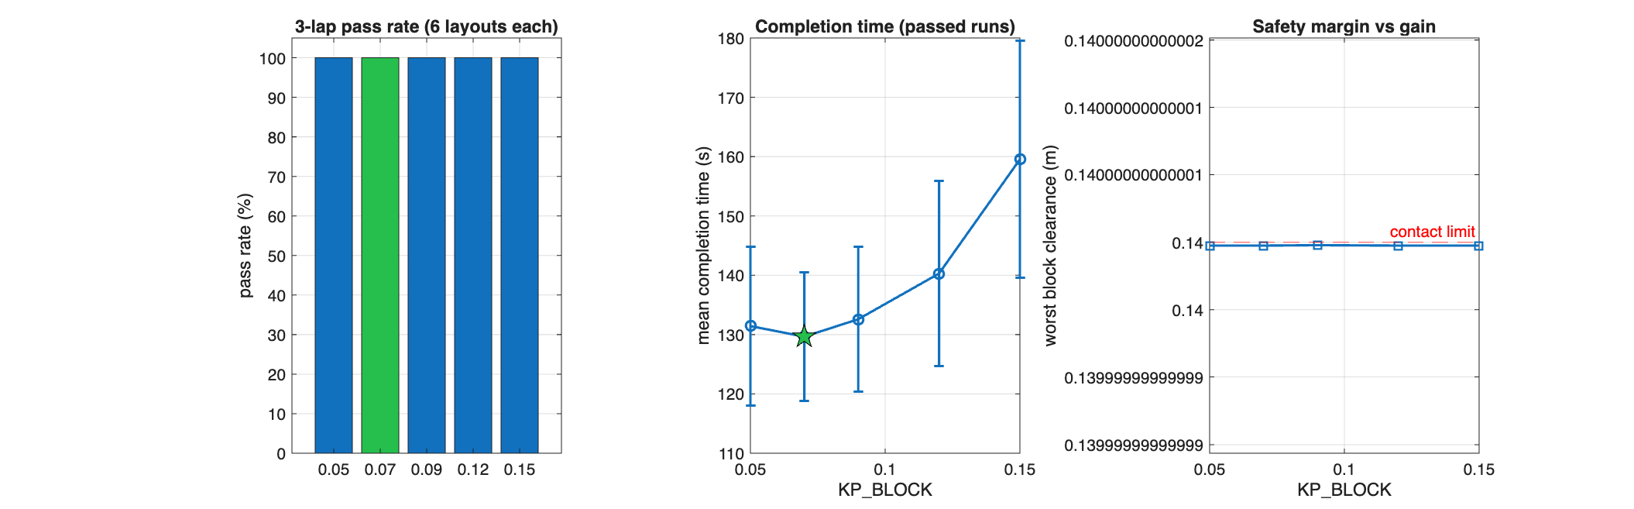
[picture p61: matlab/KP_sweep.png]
KP sweep


## How to Run

MATLAB R2024a+ with Image Processing Toolbox.

```matlab
cd matlab/obstacle_challenge
run              % interactive simulator (Randomize button between runs)
evaluate(12, 42) % batch: 12 official layouts, reproducible
sweep_kp         % steering-gain sweep (~2 min)
power_budget     % electrical checks
test_headless    % 5-second smoke test
```

## Known Limitations

Stated openly, because knowing a model's limits is part of using it:

- **Circular lane approximation** in the default navigation mode; an
  experimental port of the robot's gyro/corner logic exists
  (`P.nav_mode='gyro'`) but is not yet tournament-grade.
- **Parking entry uses a pivot turn-in** — the unicycle model rotates in
  place; the physical Ackermann car needs a reversing S-curve. Geometry and
  scoring transfer; the entry trajectory does not.
- **Idealized camera** — no noise, blur, or lighting variation, so simulated
  clearances are optimistic bounds.
- **No orange/blue line detection** — the sim counts laps geometrically.

## Conclusion

This module turns testing from "it seems to work" into engineering evidence:
our real perception strategy running in closed loop on officially randomized
layouts, scoring **12/12 complete missions with 12/12 full parallel parks and
zero contact**. It caught control bugs we would never have staged physically,
verified our power system against multimeter measurements, and bounded our
steering gain before a single physical tuning session. Every result in this
report is reproducible from this repository with one command and one seed.

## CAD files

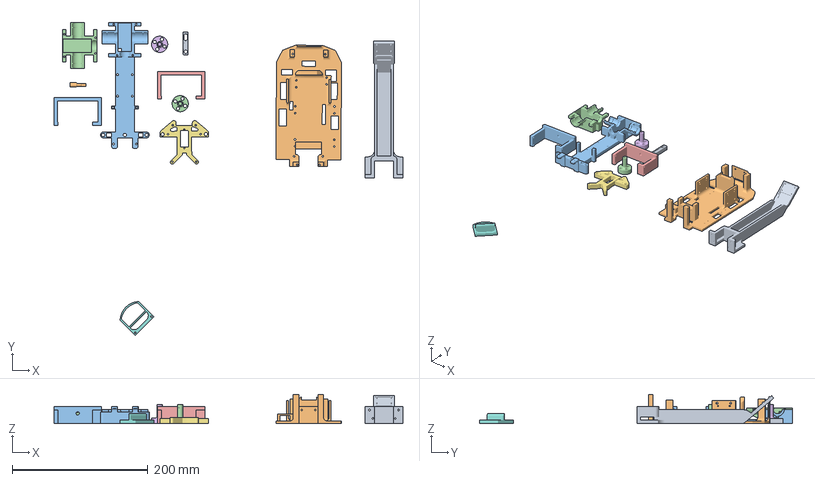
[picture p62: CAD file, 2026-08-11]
models/chassis/All_3D_Parts.3mf
515.0 x 461.9 x 43.0 mm
CameraMount.stl
TopChasis.stl
BottomChasis.stl
DifferentialMountTop.stl
WheelStabilizer.stl x 2
BearingToWheelShaft.stl x 2
ServoMount.stl
TPUBumper.stl
VariableServoHorn.stl
MotorShaft.stl

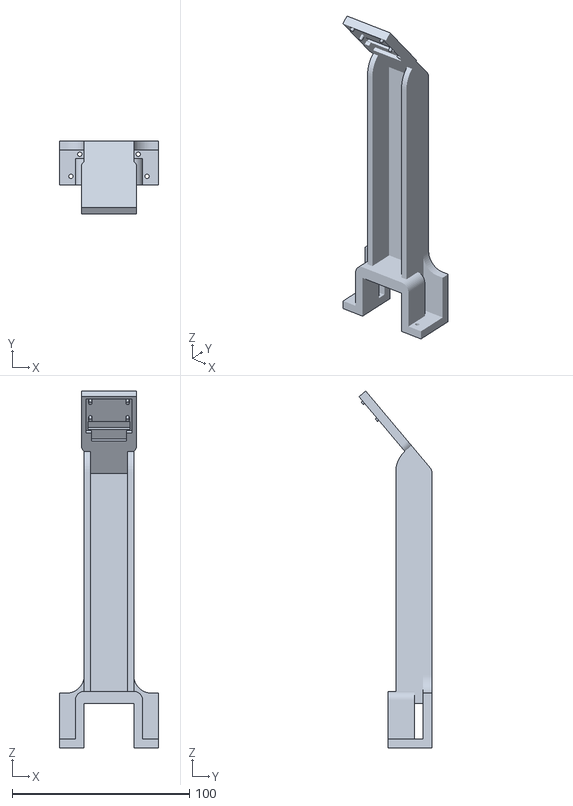
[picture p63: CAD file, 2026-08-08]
models/chassis/CameraMount.stl
56.0 x 41.3 x 201.6

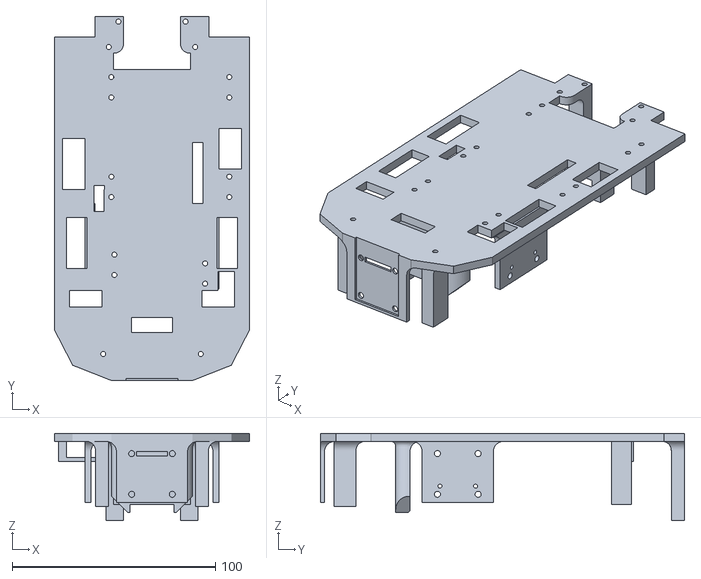
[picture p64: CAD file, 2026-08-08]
models/chassis/TopChasis.stl
96.0 x 179.0 x 43.0

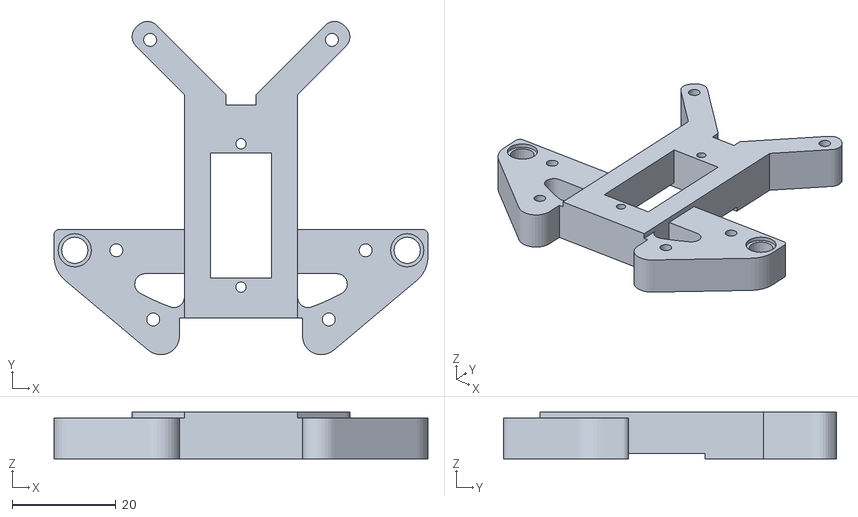
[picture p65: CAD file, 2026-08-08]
models/chassis/ServoMount.stl
72.0 x 64.1 x 9.00

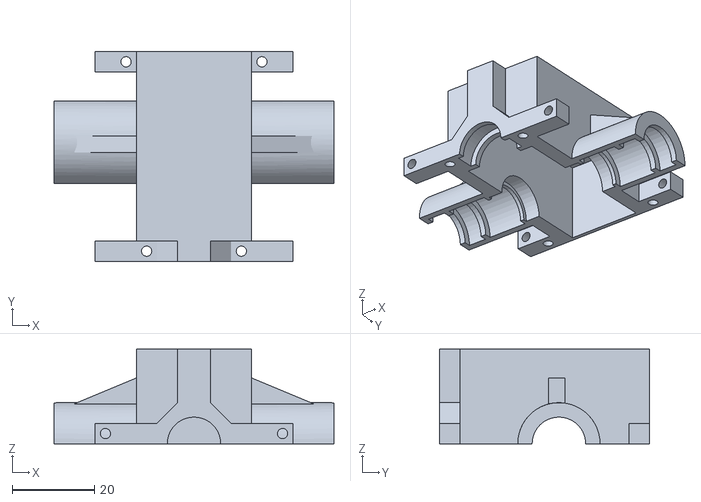
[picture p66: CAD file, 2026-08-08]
models/chassis/DifferentialMountTop.stl
68.0 x 51.0 x 23.0

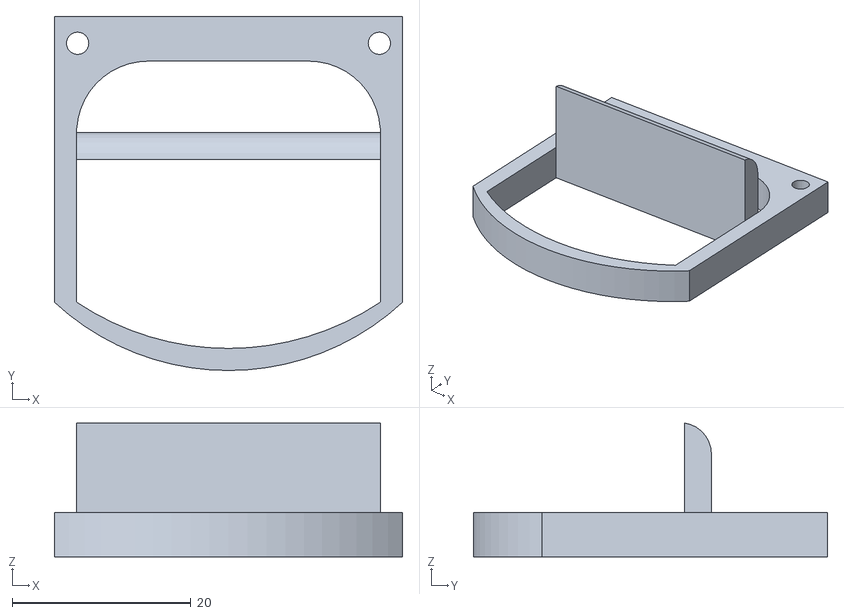
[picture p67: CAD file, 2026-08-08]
models/chassis/TPUBumper.stl
39.0 x 39.6 x 15.0

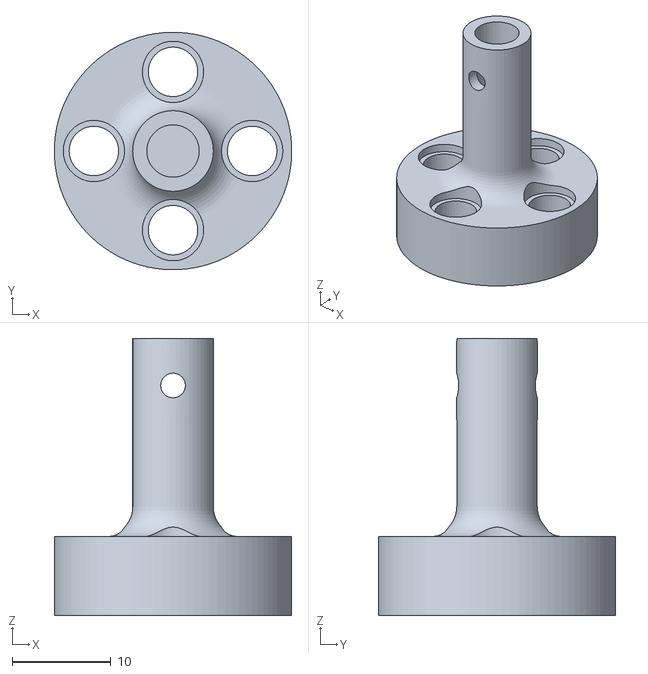
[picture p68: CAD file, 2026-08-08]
models/chassis/BearingToWheelShaft.stl
24.0 x 24.0 x 28.0

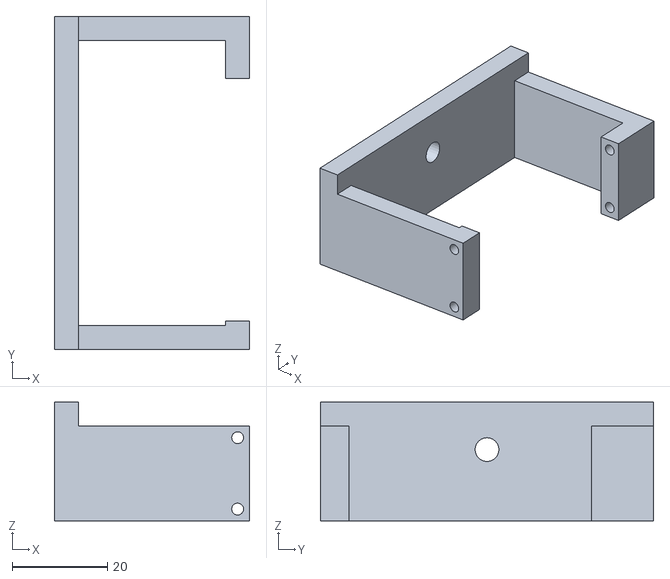
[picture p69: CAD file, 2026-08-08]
models/chassis/WheelStabilizer.stl
41.0 x 70.0 x 25.0

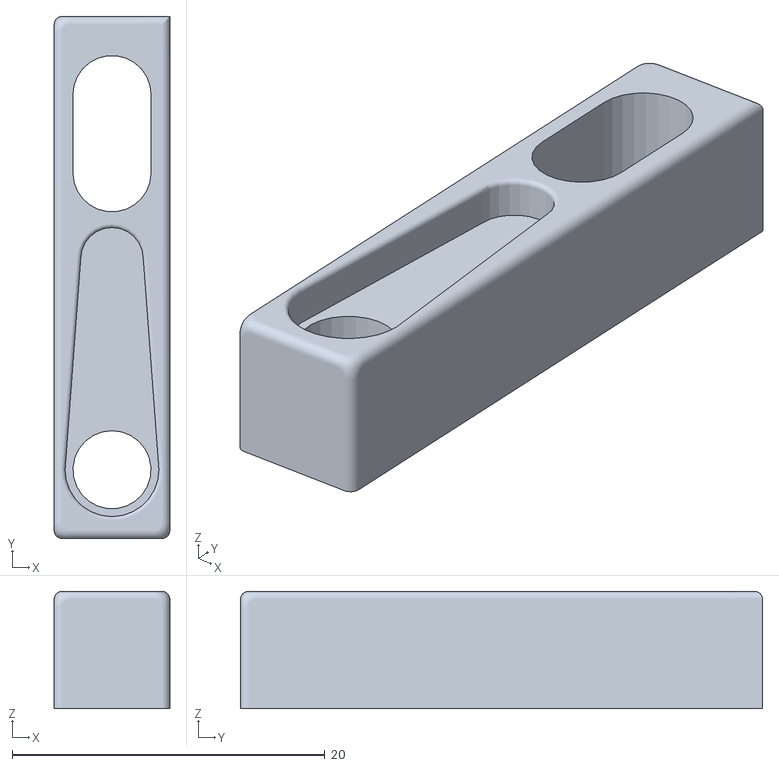
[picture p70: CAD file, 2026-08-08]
models/chassis/VariableServoHorn.stl
7.40 x 33.4 x 7.50

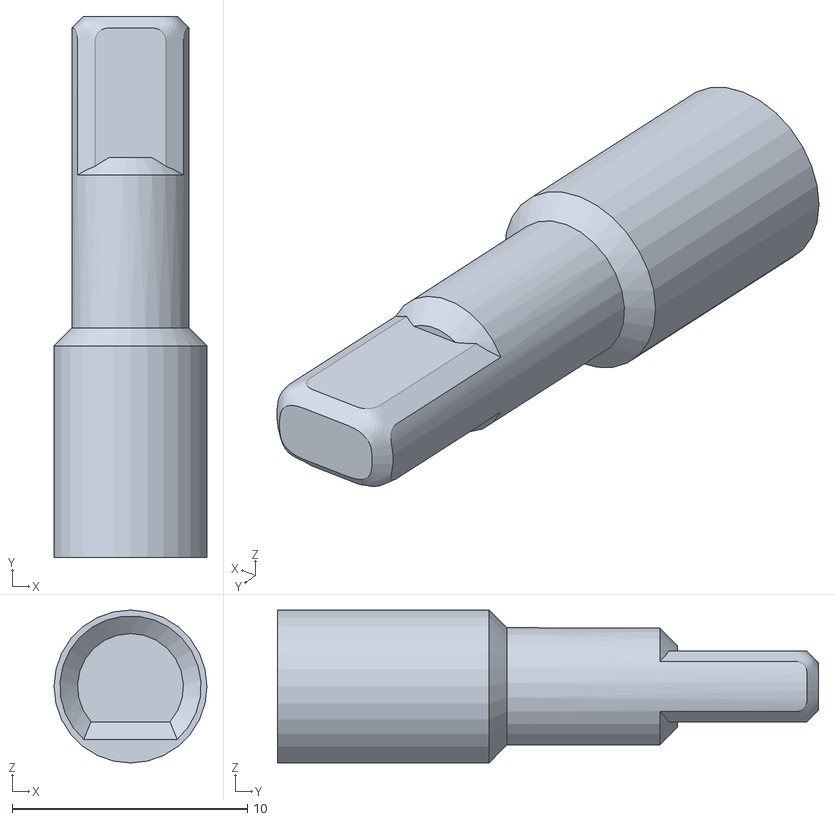
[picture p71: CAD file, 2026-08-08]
models/chassis/MotorShaft.stl
6.50 x 23.0 x 6.50

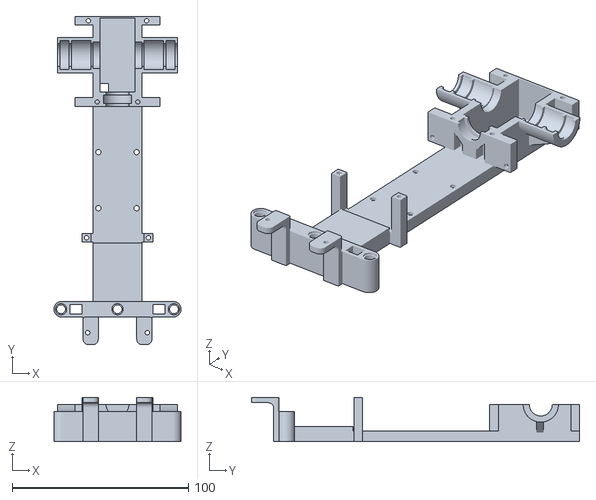
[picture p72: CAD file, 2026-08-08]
models/chassis/BottomChasis.stl
72.0 x 186.0 x 25.0

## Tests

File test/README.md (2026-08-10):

# Test (`test/`)

This folder holds the master test tracking document and the reference track layouts used for structured practice/test runs.

## Files in this folder

| File | Description |
|---|---|
| `WRO_FE_2026_Master_Test_Tracker_v2.pdf` | Master test tracker PDF — logs practice/test runs, results, and issues found across test sessions. |

## Nested folders (contents summarized here per project convention — no separate README inside)

**`master_test_layouts/`** — Reference images of the official master test-session track layouts, one pair (clockwise/counter-clockwise) per layout: `MS1_CW.png`/`MS1_CCW.png`, `MS2_CW.png`/`MS2_CCW.png`, `MS3_CW.png`/`MS3_CCW.png`, `MS4_CW.png`/`MS4_CCW.png`, `MS5_CW.png`/`MS5_CCW.png`, `MS6_CW.png`/`MS6_CCW.png`.

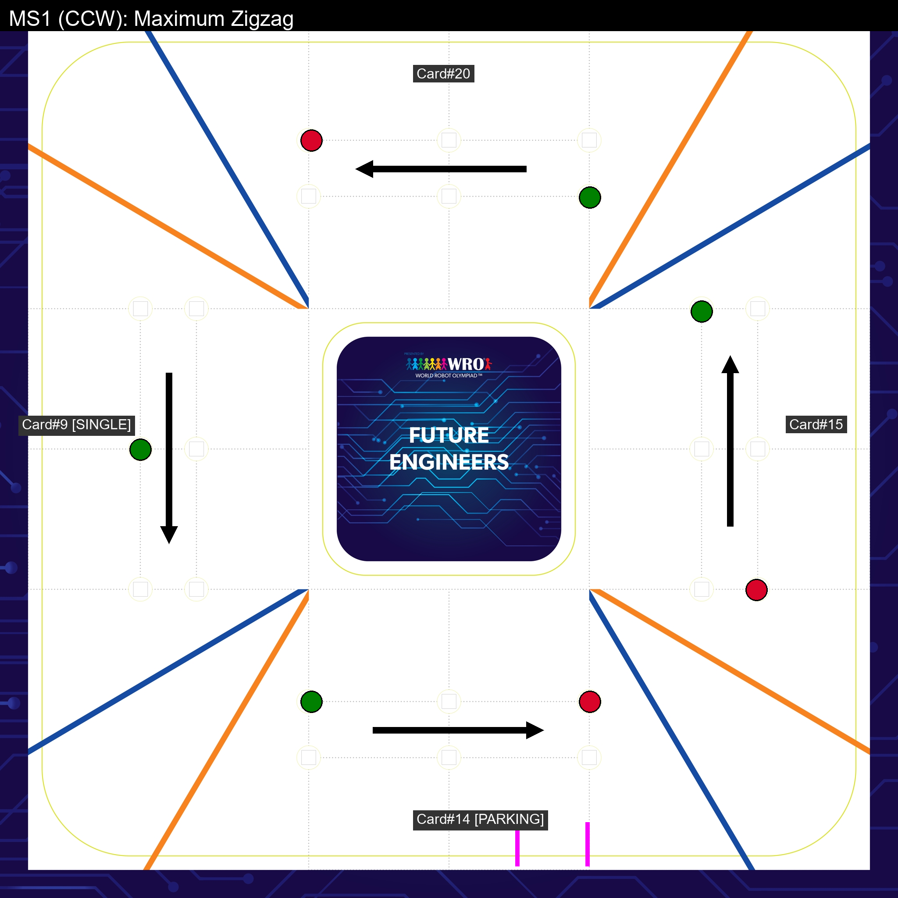
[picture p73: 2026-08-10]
test/master_test_layouts/MS1_CCW.png

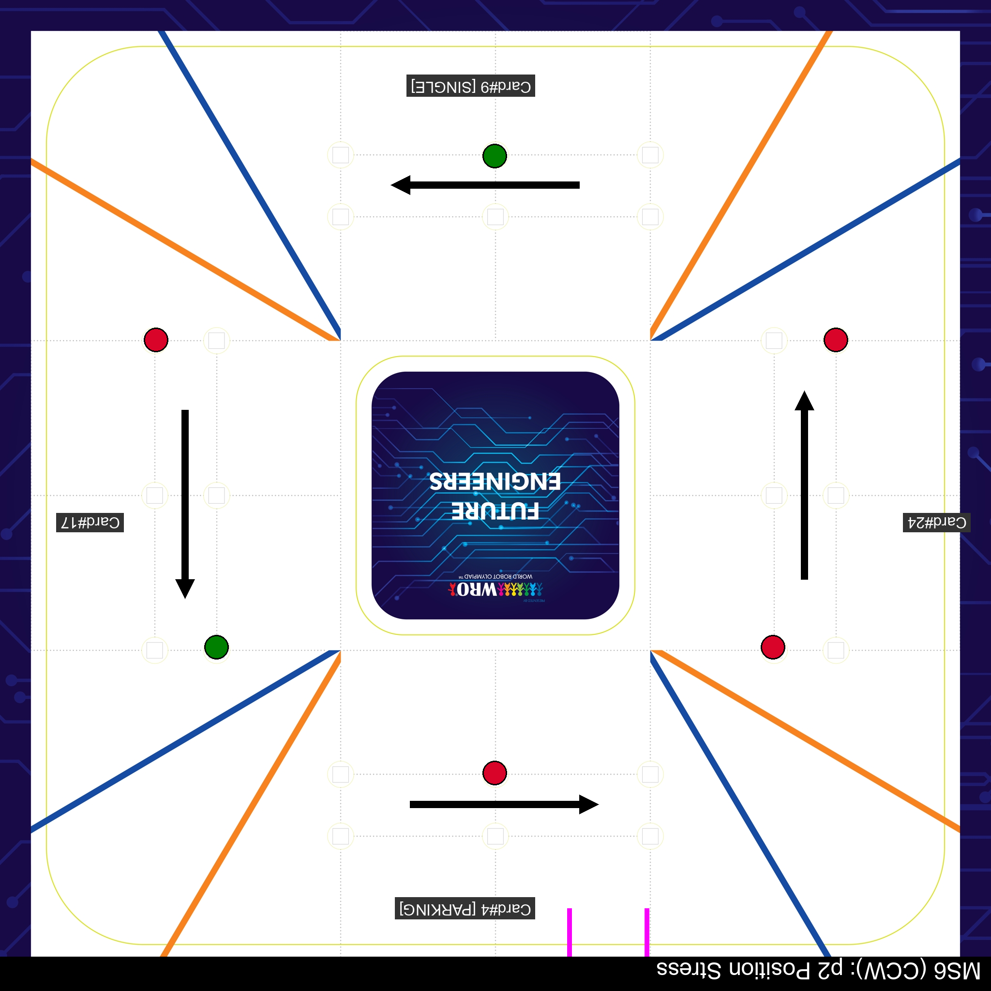
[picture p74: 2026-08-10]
test/master_test_layouts/MS6_CCW.png

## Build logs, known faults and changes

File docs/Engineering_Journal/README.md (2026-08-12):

# Engineering Journal

This Engineering Journal is a printer friendly PDF export of the soft copy version of the README.md in repo root.

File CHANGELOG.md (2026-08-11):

# Changelog

## [v2.1] - 2026-08-08 — Open Challenge complete
### Changed
Tuned open challenge in both directions for many possibilities

## [v2.0] - 2026-06-29 — Setup for WRO 2026
### Added
Code for VL53L4CD, BNO086 and quadrature encoder
Remote control code

## [v1.0] - 2025-11-28 — WRO 2025 Internationals code
### Added
Open and obstacle working perfectly, full score in all four rounds

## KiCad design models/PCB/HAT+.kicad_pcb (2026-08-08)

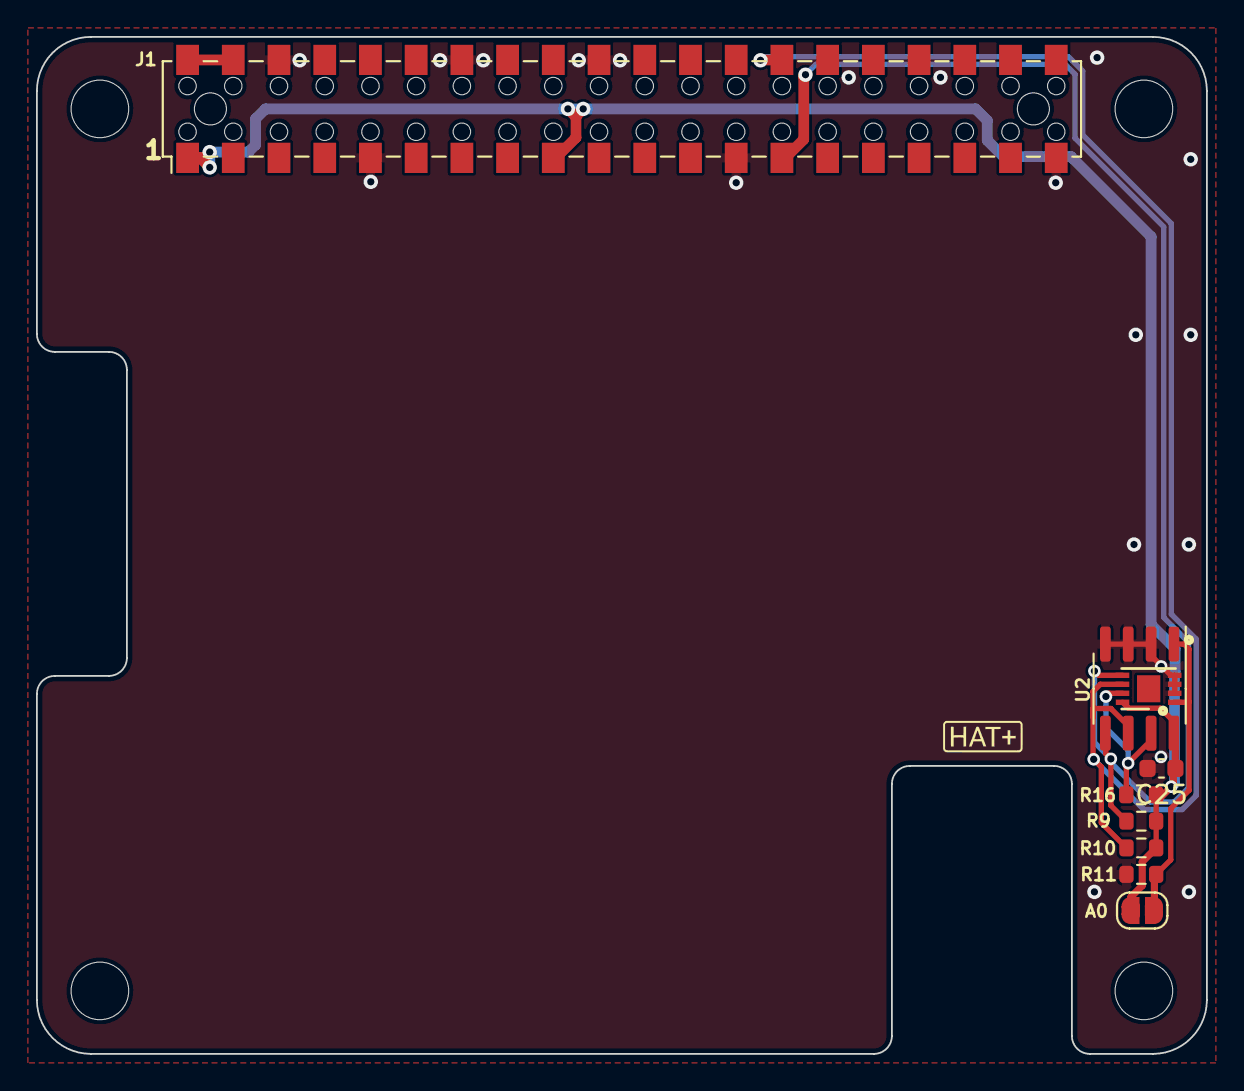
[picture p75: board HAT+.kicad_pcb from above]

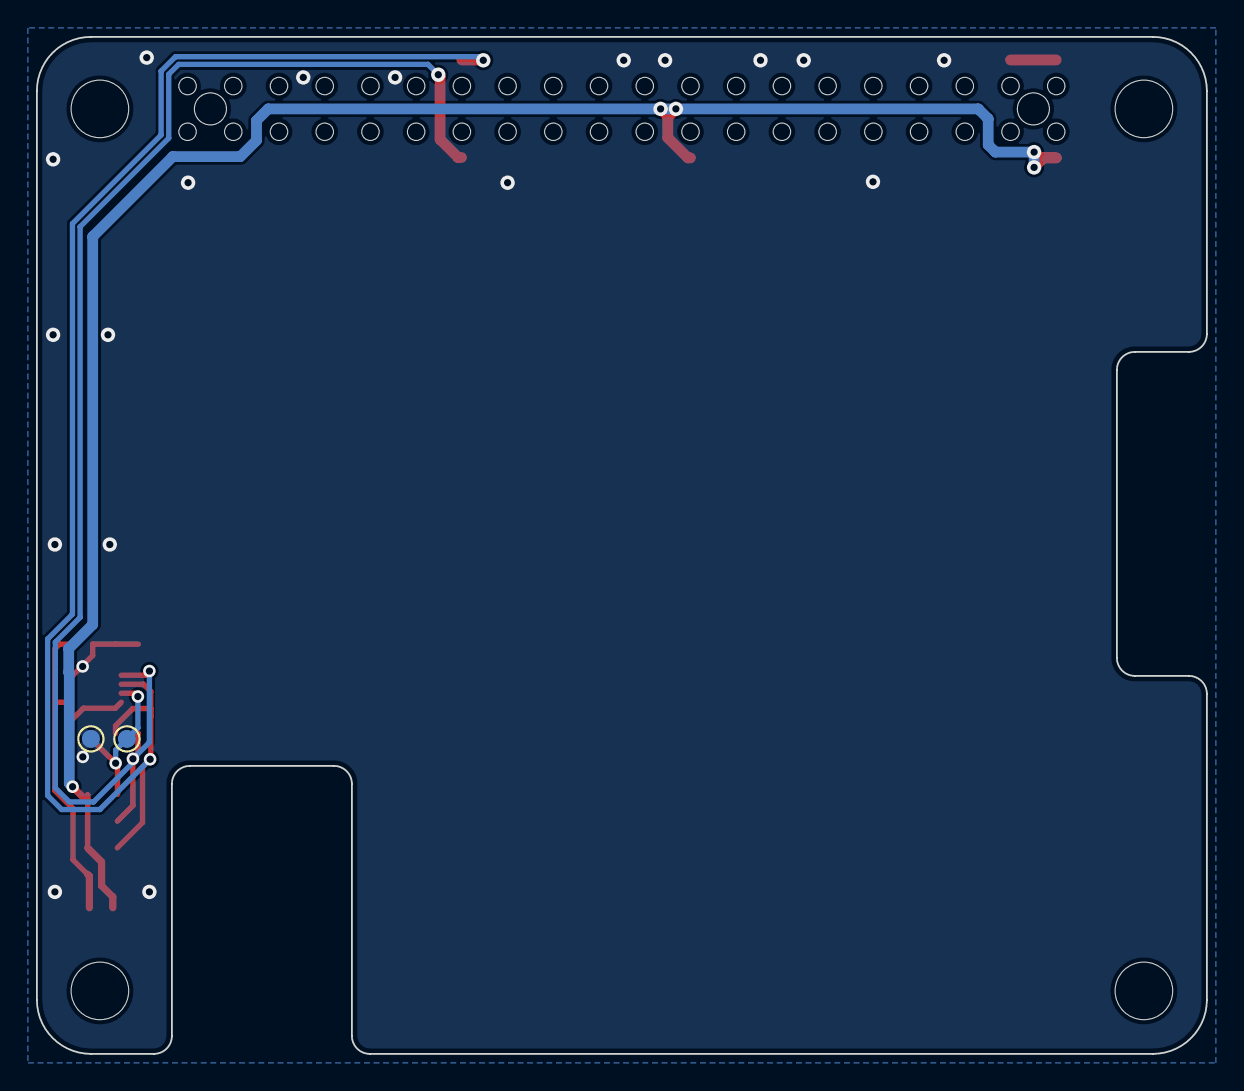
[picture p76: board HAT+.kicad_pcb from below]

Board: 4 copper layers, 65.0 x 56.5 mm, 15 parts (2 on the bottom side), 7 nets.

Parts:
A0: SolderJumper_2_Open; SolderJumper-2_P1.3mm_Open_RoundedPad1.0x1.5mm
C25: 100nF; C_0603_1608Metric
GND1: TestPoint_Alt; TestPoint_Pad_D1.0mm
H1, H2, H3, H4: MountingHole 3.2mm; MountingHole_3.2mm_M3_DIN965
J1: Conn_02x20_Odd_Even; Samtec_HLE-120-02-xxx-DV-BE-A_2x20_P2.54mm_Horizontal_Rever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
R9, R10, R11, R16: 3.9k; R_0603_1608Metric
U1: AT24CS64-SSHM; SOIC-8_3.9x4.9mm_P1.27mm
U2: AT24CS64-MAHM; DFN-8-1EP_3x2mm_P0.5mm_EP1.3x1.5mm
WP1: TestPoint_Alt; TestPoint_Pad_D1.0mm

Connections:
/HAT+/HAT_3V3: A0.2 (B), C25.1, J1.1, J1.17, R9.2, R10.2, R16.2, U1.8 (VCC), U2.8 (VCC)
/HAT+/HAT_5V0: J1.2, J1.4
/HAT+/HAT_SCL0: J1.28, R10.1, U1.6 (SCL), U2.6 (SCL)
/HAT+/HAT_SDA0: J1.27, R9.1, U1.5 (SDA), U2.5 (SDA)
GND: C25.2, GND1.1, J1.6, J1.9, J1.14, J1.20, J1.25, J1.30, J1.34, J1.39, R11.1, U1.2 (A1), U1.3 (A2), U1.4 (GND), U2.2 (A1), U2.3 (A2), U2.4 (GND)
unnamed: A0.1 (A), R11.2, U1.1 (A0), U2.1 (A0)
unnamed: R16.1, U1.7 (WP), U2.7 (WP), WP1.1

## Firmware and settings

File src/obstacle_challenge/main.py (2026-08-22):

"""
Obstacle Challenge -- main control program (v5).

Runs on the robot's Raspberry Pi 5. See CLAUDE.md for the hardware map. This file
holds the run setup and the per-frame control loop, and nothing else; everything it
calls lives in a sibling module -- vision, threads and logging are shared with the
open challenge, so they live outside this package:

    src/logs/setup.py      the `robot.*` logger tree, Throttle, non-blocking log queue
    tuning.py               every constant -- colour ranges, ROIs, gains, perf switches
    src/vision/pipeline.py  arena mask, colour masks, process_video_frame, annotation
    src/vision/pool.py      the two vision worker processes and their shared memory
    video.py                the annotated-run recorder, in its own process
    src/threads/hw_threads.py  CameraThread / ImuThread / SensorThread / PerfMonitor
    control.py              heading maths and the gyro-stabilised drive primitives
    maneuvers.py            the scripted sequences: initial maneuver, parking, parking2

Performance model (measured 2026-08-01 on the real robot, 640x360):

    camera frame interval ............ 17.7 ms   (56.0 fps, HARD sensor limit)
    process_video_frame .............. ~6.2 ms   (arena mask 3.3, colour+contours 2.5)
    annotate_video_frame ............. ~0.5 ms
    avc1 (software x264) encode ...... ~9.7 ms   (Pi 5 has NO hardware H.264 encoder)

The camera is the ceiling: the IMX708 full-FoV mode reports FrameDuration=17849us no
matter what FrameRate or FrameDurationLimits we ask for. The only faster sensor mode
(1536x864 @120fps) crops to the centre 66%, which puts the side wall-following ROIs
outside the frame. So 56 fps is the target, not something to beat.

Vision is therefore NOT the bottleneck -- it is 6.2 ms of a 17.7 ms budget. The old
loop dropped to 40-50 fps because of CPU contention, from three things this version
fixes:

  1. The loop busy-spun on `get_frame()` + `continue`, burning a whole core polling
     and starving the camera thread. Now it blocks on a condition variable.
  2. avc1 encoding ran in a *thread*, so it fought the control loop for the GIL and a
     core. Now it runs in its own process (see video.VideoEncoderProcess). avc1 is
     kept -- mp4v is cheaper but produces bigger files and won't open in QuickTime.
  3. Annotation, video write, and a `sleep(1/60 - elapsed)` all happened BEFORE
     `servo.set_angle()`, adding up to ~25 ms between seeing a frame and steering on
     it. Now the loop actuates first and records afterwards.

Multiprocessing of the vision itself (VisionPool) is a smaller, real win: the arena
mask and the colour thresholding are independent until they meet at a bitwise_and, so
they fork-join across two processes. Measured 5.19 ms -> 4.17 ms (1.25x). The split is
fork-join, NOT a pipeline -- a pipeline would raise latency, which is the opposite of
what we want. Frames move through /dev/shm (0.05 ms memcpy); a Queue/pickle path would
cost more than the work saved.

Run it from the repo root:  python3 -m src.obstacle_challenge.main
"""

import argparse
import math
import os
import sys
import time
from collections import deque
from datetime import datetime

import cv2
import numpy as np
import threading
from gpiozero import Button, LED
import subprocess

from src.motors import motor, servo
from src.sensors import bno086, camera, distance

from src.obstacle_challenge import config, control, maneuvers
from src.threads.hw_threads import (
    CameraThread, ImuThread, PerfMonitor, SensorThread,
)
from src.logs.setup import Throttle, log, setup_logging, shutdown_logging
from src.obstacle_challenge.tuning import *
from src.obstacle_challenge.video import OverlayLog, VideoEncoderProcess
from src.tools.annotate_run import BackgroundAnnotator, annotate_run
from src.tools.power_mode import ensure_performance
from src.vision import pipeline as vision
from src.vision.pipeline import annotate_video_frame, process_video_frame
from src.vision.pool import VisionPool


if __name__ == "__main__":
    parser = argparse.ArgumentParser(description="Obstacle Challenge main control program.")
    parser.add_argument(
        "-b", "--button",
        action="store_true",
        help="Wait for hardware button press before starting the run."
    )
    parser.add_argument(
        "-v", "--raw-video",
        action="store_true",
        help="Record raw.mp4 -- untouched camera frames -- INSTEAD OF the annotated "
             "obstacle.mp4, and log what was detected alongside it. obstacle.mp4 is "
             "rebuilt automatically in the background as soon as turn 13 completes and "
             "parking begins (see --no-annotate), so you still get both videos and the "
             "program exits the instant parking finishes. Cheaper on the control loop "
             "than annotating live, and raw.mp4 is what the colour tuners want."
    )
    parser.add_argument(
        "--no-annotate",
        action="store_true",
        help="With -v, do NOT rebuild obstacle.mp4 at all. Normally the rebuild starts "
             "in the background the moment parking begins and overlaps with parking's "
             "idle CPU time (pausing during parking's own camera-tracking step), so it "
             "already costs the run nothing; use this only if you don't want "
             "obstacle.mp4 this run and will rebuild later."
    )
    parser.add_argument(
        "--every-n", type=int, default=None, metavar="N",
        help=f"Record every Nth frame (default {VIDEO_EVERY_N}). N=1 records all 56 fps "
             "but measurably starves the vision workers -- loop work p50 goes 8.6 -> "
             "12.2 ms and p95 to 20.2 ms, past the 17.9 ms frame budget -- so expect to "
             "drop below 56 fps. Raise it to shrink the recording instead."
    )
    args = parser.parse_args()

    run_timestamp = datetime.now().strftime("%Y-%m-%d_%H-%M-%S")
    base_folder = "obstacle"
    run_folder = os.path.join(base_folder, run_timestamp)
    os.makedirs(run_folder, exist_ok=True)
    video_path = os.path.join(run_folder, 'obstacle.mp4')
    raw_video_path = os.path.join(run_folder, 'raw.mp4')
    log_path = os.path.join(run_folder, 'obstacle_output.txt')

    setup_logging(log_path)
    log.info("=== Obstacle Challenge v5 | run %s ===", run_timestamp)
    log.info("Logging to %s", log_path)
    if args.raw_video:
        log.info("Raw video recording (-v): storing untouched frames -> %s. "
                 "Rebuild the annotated video with "
                 "`python3 -m src.obstacle_challenge.annotate_run %s`",
                 raw_video_path, run_folder)

    # If the between-runs idle-power trim is still active (powersave governor),
    # undo it now -- before any latency-sensitive work starts.
    ensure_performance(log)

    # ---- Child processes FIRST -------------------------------------------
    # These are forked, and fork copies the parent's whole address space. Forking
    # after picamera2/lgpio/gpiozero have opened device handles, or after threads
    # exist, hands the child invalid state -- hangs and double-frees. So the pool
    # and the encoder are created before any hardware is touched and before any
    # thread is started.
    vision_pool = None
    if USE_VISION_POOL:
        vision_pool = VisionPool()
        vision_pool.start()
        # process_video_frame() reads this; setting it is what switches the
        # pipeline from inline to pooled.
        vision.vision_pool = vision_pool
        # Workers own a core each; leave the main process fewer OpenCV threads so
        # they don't oversubscribe the 4 cores.
        cv2.setNumThreads(2)
    else:
        cv2.setNumThreads(4)
        log.info("VisionPool disabled; processing inline.")

    # Exactly ONE encoder either way. -v swaps what it stores (untouched frames rather
    # than annotated ones) instead of adding a second process; see video.py for why a
    # second x264 instance is not affordable on 4 cores.
    record_raw = args.raw_video
    video_encoder = VideoEncoderProcess(
        raw_video_path if record_raw else video_path, VIDEO_FOURCC,
        every_n=args.every_n)
    video_encoder.start()
    log.info("Recording %s to %s (%s)", "raw" if record_raw else "annotated",
             video_encoder.path, VIDEO_FOURCC)
    # Control state the rebuilt annotation needs and cannot recover from pixels.
    overlay_log = OverlayLog(raw_video_path) if record_raw else None

    # A second, always-idle encoder for parking's own footage. Started here (before
    # any hardware/thread exists) for the same fork-safety reason as video_encoder
    # above -- parking begins mid-run, long after threads and picamera2 are up, so
    # this cannot be created lazily at that point. It sits at 0 frames/0% CPU for the
    # entire drive; parking.py only starts writing to it once turn 13 is reached, so
    # the driving video never has to share space with parking's telemetry overlay --
    # see _record_parking() in maneuvers.py.
    parking_video_path = os.path.join(run_folder, 'parking.mp4')
    parking_video_encoder = VideoEncoderProcess(
        parking_video_path, VIDEO_FOURCC, every_n=args.every_n)
    parking_video_encoder.start()
    log.info("Recording parking footage to %s (%s)", parking_video_path, VIDEO_FOURCC)

    # ---- Hardware ---------------------------------------------------------
    if not camera.initialize():
        # Most common cause: something else (a colour tuner, another run) still has
        # the camera open -- picamera2 fails init but capture_frame() would then just
        # return None forever, so the run would drive fully blind instead of erroring.
        # Bail out now, before any motor/servo/thread is touched, and clean up the
        # three processes already started above.
        log.error("Camera failed to initialize (already in use by another process?). "
                  "Aborting run before touching motors/threads.")
        try:
            video_encoder.stop()
        except Exception:
            log.exception("Error stopping encoder")
        try:
            parking_video_encoder.stop()
        except Exception:
            log.exception("Error stopping parking encoder")
        if overlay_log is not None:
            overlay_log.close()
        if vision_pool is not None:
            try:
                vision_pool.stop()
            except Exception:
                log.exception("Error stopping vision pool")
        shutdown_logging()
        sys.exit(1)
    motor.initialize()
    servo.initialize()
    button = Button(config.BUTTON_PIN)
    led = LED(config.LED_PIN)

    orange_detection_history = deque([False] * ORANGE_DETECTION_HISTORY_LENGTH, maxlen=ORANGE_DETECTION_HISTORY_LENGTH)
    cooldown_frames = 0
    orange_detection_history.append(False)
    turn_counter = 0
    angle = 0
    prevangle = 0
    prev_rpm = 0
    prev_wall_error = 0.0

    camera_thread = CameraThread(camera)
    camera_thread.start()

    sensors_initialized_event = threading.Event()
    sensor_thread = SensorThread(distance, sensors_initialized_event)
    sensor_thread.start()

    imu_initialized_event = threading.Event()
    imu_thread = ImuThread(bno086, imu_initialized_event)
    imu_thread.start()

    log.info("Waiting for distance sensors and IMU to initialize...")
    sensors_initialized_event.wait()
    log.info("Sensors are ready.")
    imu_initialized_event.wait()
    log.info("IMU is ready. Locking dynamic calibration for run...")
    imu_thread.lock_calibration()
    log.info("Proceeding with main logic.")
    led.on()
    if args.button:
        log.info("Waiting for button press...")
        button.wait_for_press()
        log.info("Button pressed! Starting run.")
        led.off()
        time.sleep(1)
    led.off()
    subprocess.run(["pinctrl", "FAN_PWM", "op", "dl"], check=False)
    driving_direction = 'clockwise'
    past_frame_counter = 0
    max_direction_frames = 60
    consecutive_required = 3
    candidate_direction = None
    consecutive_count = 0

    log.info("Detecting start driving direction from camera frames...")
    for _ in range(max_direction_frames):
        frame, past_frame_counter, _, fresh = camera_thread.get_next_frame(past_frame_counter)
        if frame is None or not fresh:
            # Stale frame -- re-running detection on pixels already counted would
            # let one frame satisfy `consecutive_required` on its own.
            continue

        detections = process_video_frame(frame)
        wall_inner_left_size = sum(obj['area'] for obj in detections.get('detected_walls', []) if obj['type'] == 'wall_inner_left')
        wall_inner_right_size = sum(obj['area'] for obj in detections.get('detected_walls', []) if obj['type'] == 'wall_inner_right')

        if wall_inner_left_size == 0 and wall_inner_right_size == 0:
            current_dir_label = "unknown"
            consecutive_count = 0
            log.debug("Direction detect: 0 px on both sides (left=0, right=0), waiting for more frames...")
        elif wall_inner_left_size > wall_inner_right_size:
            current_dir_label = "clockwise"
            if candidate_direction == current_dir_label:
                consecutive_count += 1
            else:
                candidate_direction = current_dir_label
                consecutive_count = 1
        elif wall_inner_right_size > wall_inner_left_size:
            current_dir_label = "counter-clockwise"
            if candidate_direction == current_dir_label:
                consecutive_count += 1
            else:
                candidate_direction = current_dir_label
                consecutive_count = 1
        else:
            current_dir_label = "equal"
            consecutive_count = 0

        debug_items = [
            f"StartDir:{current_dir_label}",
            f"L:{int(wall_inner_left_size)}",
            f"R:{int(wall_inner_right_size)}",
        ]

        # Record direction detection frames into the video
        if record_raw:
            if video_encoder.write(frame, tag=past_frame_counter):
                if overlay_log is not None:
                    overlay_log.append(
                        len(video_encoder.tags) - 1,
                        current_dir_label,
                        debug_items,
                        visual_target_x=None,
                        visual_target_line=None,
                        detections=detections,
                    )
        else:
            video_encoder.write(
                frame, tag=past_frame_counter,
                prepare=lambda f, det=detections, d_dir=current_dir_label, dbg=debug_items: annotate_video_frame(
                    f, det, d_dir,
                    debug_info=dbg,
                    visual_target_x=None,
                    visual_target_line=None,
                ),
            )

        log.info("Direction detect frame - left: %.0f, right: %.0f -> candidate: %s (%d/%d)",
                 wall_inner_left_size, wall_inner_right_size,
                 current_dir_label, consecutive_count, consecutive_required)

        if candidate_direction is not None and consecutive_count >= consecutive_required:
            driving_direction = candidate_direction
            break

    if candidate_direction is not None and consecutive_count < consecutive_required:
        driving_direction = candidate_direction
        log.warning("Direction detection reached max frames without full consensus, using last candidate: %s", driving_direction)
    elif candidate_direction is None:
        log.warning("Direction detection found 0 px on both sides across %d frames, defaulting to clockwise",
                    max_direction_frames)
        driving_direction = 'clockwise'

    log.info("Decided driving direction: %s", driving_direction)

    INITIAL_HEADING = None
    while INITIAL_HEADING is None:
        heading = imu_thread.get_heading()
        if heading is not None:
            INITIAL_HEADING = heading
            break
        log.debug("Waiting for first valid heading reading...")
        time.sleep(0.05)
    log.info("Initial heading locked: %.1f°", INITIAL_HEADING)

    # Hand the scripted sequences the live objects and run-level values they read.
    # Everything they need now exists; nothing below may rebind these.
    control.bind(imu_thread=imu_thread)
    maneuvers.bind(
        camera_thread=camera_thread,
        imu_thread=imu_thread,
        sensor_thread=sensor_thread,
        video_encoder=video_encoder,
        parking_video_encoder=parking_video_encoder,
        # Tells the maneuvers to record untouched frames too -- several of them draw
        # straight onto the frame they write, which would poison raw.mp4.
        RECORD_RAW=record_raw,
        overlay_log=overlay_log,
        INITIAL_HEADING=INITIAL_HEADING,
        driving_direction=driving_direction,
    )

    perf = PerfMonitor()

    # Set once turn 13 starts the background rebuild (see the turn_counter >= 13
    # branch below). Declared here, before the run can fail, so the `finally` block
    # can tell "rebuild already started in the background" apart from "never reached
    # turn 13" -- an aborted run (exception, or the stop button before turn 13) needs
    # the old synchronous rebuild as a fallback, since nothing else will have done it.
    bg_annotator = None

    try:
        run_start_time = time.monotonic()
        past_frame_counter = 0
        frame_counter = 0
        maneuvers.perform_initial_maneuver()
        log.info("Initial maneuver done; entering main control loop.")

        motor.start_rpm_control(INITIAL_RPM, "forward")
        # Same detail is already in the overlay JSON (one record per recorded frame,
        # replayable by annotate_run.py), so this is just a coarse human-readable
        # heartbeat -- throttled hard to keep the log file grep-able.
        frame_debug_throttle = Throttle(1.0)
        prev_rpm = INITIAL_RPM
        last_block_target_rpm = INITIAL_RPM
        frames_since_block_seen = BLOCK_TARGET_GRACE_FRAMES
        loop_frames = 0
        tracking_green_block = False
        green_post_pass_frames = 0
        tracking_red_block = False
        red_post_pass_frames = 0
        prev_target_error = 0.0
        camera_stalled = False

        while True:
            target_rpm = INITIAL_RPM
            angle = 0
            active_block_y = None
            debug = []
            visual_target_x = None
            visual_target_line = None

            # Blocking wait -- no busy-spin. `capture_ts` is when the camera thread
            # actually received this frame, which is what capture->servo latency is
            # measured against.
            frame, frame_counter, capture_ts, fresh = camera_thread.get_next_frame(past_frame_counter)
            if frame is None or not fresh:
                # No new frame within CAMERA_STALE_TIMEOUT_S. `frame` is the one we
                # already steered on, so acting again means acting on pixels that
                # are at least that old while the robot keeps rolling at ~1 m/s.
                # Cut power and hold here -- unlike a post-hoc `skipped` check this
                # runs DURING the stall, which is the only time it can help.
                if not camera_stalled:
                    camera_stalled = True
                    log.critical(
                        "CAMERA STALL: no new frame for >%.0f ms after f=%d -- "
                        "stopping motor and holding until frames resume.",
                        CAMERA_STALE_TIMEOUT_S * 1000.0, past_frame_counter)
                    motor.stop_rpm_control()
                    motor.brake()
                # Still honour the stop button, or a dead camera would hang the run
                # with no way out.
                if button.is_pressed:
                    log.info("Stop button pressed during camera stall -- ending run.")
                    break
                continue

            skipped = max(0, frame_counter - past_frame_counter - 1)
            if camera_stalled:
                camera_stalled = False
                log.warning("CAMERA STALL over: frames resumed after %d skipped "
                            "(~%.0f ms blind); restarting motor control.",
                            skipped, skipped / CAMERA_FPS * 1000.0)
                # Restart from the same state entry into the loop uses, so the rate
                # limiter ramps back up from INITIAL_RPM rather than jumping to
                # whatever target was in flight when the camera died.
                motor.start_rpm_control(INITIAL_RPM, "forward")
                prev_rpm = INITIAL_RPM
                last_block_target_rpm = INITIAL_RPM
                frames_since_block_seen = BLOCK_TARGET_GRACE_FRAMES
            past_frame_counter = frame_counter
            loop_frames += 1

            sensor_readings = sensor_thread.get_readings()

            t_proc = time.perf_counter()
            detections = process_video_frame(frame)
            proc_ms = (time.perf_counter() - t_proc) * 1000.0
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

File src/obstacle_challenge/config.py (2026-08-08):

import numpy as np


TILT_THRESHOLD_DEGREES = 15.0


DRIVE_SPEED = 100.0


FRAME_WIDTH = 640
FRAME_HEIGHT = 480
MAX_FPS = 30
CROP_TOP_FRAC = 0
CROP_BOTTOM_FRAC = 0
MIN_CONTOUR_AREA = 2500
MAX_BLOCK_AREA_FRACTION = 0.25
MIN_BLOCK_ROI_OVERLAP = 0.50


MIN_BLOCK_AREA_FOR_ACTION = 7500
MANEUVER_ANGLE_DEG = 45.0
MIN_FRAMES_IN_TURN = 30
TOTAL_TURNS = 12
MANEUVER_DRIVE_FRAMES_SIDEWAYS = 10
MANEUVER_DRIVE_FRAMES_STRAIGHT = 0
SPECIAL_TURN_SIDEWAYS_FRAMES = 0


CCW_TURN_ANGLE = 90.0
CCW_SCAN_ANGLE = 60.0
CCW_NORMAL_DRIVE_FRAMES = 25
CCW_REVERSE_FRAMES = 10
CCW_SHORT_DRIVE_FRAMES = 0


CW_DRIVE_FORWARD_RED_FRAMES = 25
CW_REVERSE_GREEN_FRAMES = 15
CW_DRIVE_FORWARD_NONE_FRAMES = 0

GYRO_ENABLED = True
GYRO_KP = 3.0
HEADING_LOCK_TOLERANCE = 5.0
INVERT_GYRO = True


TOF_ENABLED = True
TOF_CHANNELS_TO_USE = range(1,4)
TOF_FORWARD_SENSOR_CHANNEL = 1
TOF_CORNERING_THRESHOLD_MM = 240
TOF_OBSTACLE_THRESHOLD_MM = 100
WALL_FOLLOW_KP = 0.2


BUTTON_PIN = 23
LED_PIN = 12

AIN1_PIN = 26
AIN2_PIN = 13
STBY_PIN = 6
# The motor's two leads are reversed relative to the TB6612's A01/A02 outputs,
# and they're soldered to the PCB so they can't be swapped back. Inverting here
# makes forward() drive the robot forwards.
# Changed to False to reverse the direction as requested (motor went backward when told forward).
MOTOR_DIR_INVERT = False
MOTOR_PWM_PIN = 19
MOTOR_PWM_FREQ = 1000
MOTOR_PWM_CHIP = 0
MOTOR_PWM_CHANNEL = 3
SERVO_GPIO = 18
# Raised from the standard 50Hz to cut command-update quantization (20ms->12.5ms).
# Pulse widths below are absolute (seconds) and SERVO_PWM_PERIOD_S is derived from
# this, so center/endpoint calibration is unaffected -- verified identical 1.489ms
# pulse across frequencies.
#
# The ES08A II is an ANALOG servo and EMAX publishes no max refresh rate. 80Hz is
# the highest rate with reported headroom: analog servos drive the motor with a
# pulse proportional to position error, and once that drive pulse approaches the
# update interval the internal loop goes unstable. Reported behaviour on analog
# servos is 80Hz good / 90Hz marginal / 100Hz oscillating -- and the instability
# shows up on LARGE steps (our 55deg close-block swing), not at rest, so it will
# not necessarily reveal itself on a stationary bench test.
# If steering hunts or buzzes during big swings, drop back to 50.
SERVO_PWM_FREQ = 80
SERVO_PWM_CHIP = 0
SERVO_PWM_CHANNEL = 2
CALIBRATED_MIN_PW_S = 0.001
CALIBRATED_MAX_PW_S = 0.002
CALIBRATED_ANGLE_MIN = 42.5
CALIBRATED_ANGLE_MAX = 137.5
INPUT_ANGLE_MIN_SERVO = -47.5
INPUT_ANGLE_MAX_SERVO = 47.5
SERVO_CENTER_OFFSET = -1.0
SAFETY_MIN_PW_S = 0.0007
SAFETY_MAX_PW_S = 0.0023
SERVO_PWM_PERIOD_S = 1.0 / SERVO_PWM_FREQ


BOX_COLOR_RED = (0, 0, 255)
BOX_COLOR_GREEN = (0, 255, 0)
BOX_COLOR_ROI = (255, 0, 255)

LOWER_RED_1 = np.array([0, 100, 55])
UPPER_RED_1 = np.array([5, 255, 255])
LOWER_RED_2 = np.array([174, 100, 55])
UPPER_RED_2 = np.array([180, 255, 255])

LOWER_GREEN = np.array([40, 60, 40])
UPPER_GREEN = np.array([80, 255, 180])

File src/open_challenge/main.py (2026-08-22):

"""
Open Challenge -- main control program.

Shares its whole vision pipeline and multiprocessing model with the obstacle
challenge (see CLAUDE.md and src/vision/pipeline.py / src/vision/pool.py):
the same `process_video_frame()` -- arena mask + colour thresholding
fork-joined across two worker processes via VisionPool -- the same
CameraThread/ImuThread (src/threads/hw_threads.py), the same
VideoEncoderProcess for recording, and the same `robot.*` logging pipeline
(src/logs/setup.py). Only the driving logic below is open-challenge specific
(no pillars, no parking).

process_video_frame() also detects pillars and the parking (magenta) walls,
which don't exist on the open track -- `detected_blocks` and
`detected_magenta` simply come back empty every frame, which this loop never
reads.

Run it from the repo root:  python3 -m src.open_challenge.main
"""

import argparse
import math
import os
import threading
import time
from collections import deque
from datetime import datetime

import cv2
import numpy as np
from gpiozero import Button, LED

from src.motors import motor, servo
from src.sensors import bno086, camera

from src.open_challenge import config
from src.open_challenge.config import *
from src.obstacle_challenge.control import get_angular_difference
from src.obstacle_challenge.tuning import CAMERA_STALE_TIMEOUT_S
from src.threads.hw_threads import CameraThread, ImuThread, PerfMonitor
from src.logs.setup import Throttle, log, setup_logging, shutdown_logging
from src.obstacle_challenge.video import VideoEncoderProcess
from src.tools.power_mode import ensure_performance
from src.vision import pipeline as vision
from src.vision.pipeline import annotate_video_frame, process_video_frame
from src.vision.pool import VisionPool


if __name__ == "__main__":
    parser = argparse.ArgumentParser(description="Open Challenge main control program.")
    parser.add_argument(
        "-b", "--button",
        action="store_true",
        help="Wait for hardware button press before starting the run."
    )
    args = parser.parse_args()

    run_timestamp = datetime.now().strftime("%Y-%m-%d_%H-%M-%S")
    base_folder = "open"
    run_folder = os.path.join(base_folder, run_timestamp)
    os.makedirs(run_folder, exist_ok=True)
    video_path = os.path.join(run_folder, 'open.mp4')
    log_path = os.path.join(run_folder, 'open_output.txt')

    setup_logging(log_path)
    log.info("=== Open Challenge | run %s ===", run_timestamp)
    log.info("Logging to %s", log_path)

    # If the between-runs idle-power trim is still active (powersave governor),
    # undo it now -- before any latency-sensitive work starts.
    ensure_performance(log)

    # ---- Configure vision pipeline for Open Challenge ----
    vision.configure(config)

    # ---- Child processes FIRST -------------------------------------------
    # Same ordering constraint as the obstacle challenge: fork before any
    # hardware handle or thread exists (see src/obstacle_challenge/main.py).
    vision_pool = None
    if USE_VISION_POOL:
        vision_pool = VisionPool()
        vision_pool.start()
        vision.vision_pool = vision_pool
        cv2.setNumThreads(2)
    else:
        cv2.setNumThreads(4)
        log.info("VisionPool disabled; processing inline.")

    video_encoder = VideoEncoderProcess(video_path, VIDEO_FOURCC)
    video_encoder.start()
    log.info("Recording to %s (%s)", video_path, VIDEO_FOURCC)

    # ---- Hardware ---------------------------------------------------------
    camera.initialize()
    motor.initialize()
    servo.initialize()
    button = Button(config.BUTTON_PIN)
    led = LED(config.LED_PIN)

    camera_thread = CameraThread(camera)
    camera_thread.start()

    imu_initialized_event = threading.Event()
    imu_thread = ImuThread(bno086, imu_initialized_event)
    imu_thread.start()
    log.info("Waiting for IMU to initialize...")
    imu_initialized_event.wait()
    log.info("IMU is ready. Proceeding with main logic.")

    led.on()
    if args.button:
        log.info("Waiting for button press...")
        button.wait_for_press()
        log.info("Button pressed! Starting run.")
    led.off()
    time.sleep(0.5)

    INITIAL_HEADING = None
    while INITIAL_HEADING is None:
        log.debug("Waiting for first valid heading reading...")
        heading = imu_thread.get_heading()
        if heading is not None:
            INITIAL_HEADING = heading
        time.sleep(0.05)
    log.info("Initial heading locked: %.1f", INITIAL_HEADING)

    orange_detection_history = deque([False] * ORANGE_DETECTION_HISTORY_LENGTH, maxlen=ORANGE_DETECTION_HISTORY_LENGTH)
    cooldown_frames = 0
    turn_counter = 0

    prev_angle = 0
    prev_wall_error = 0.0
    past_frame_counter = 0
    # Set from the first floor line we see: orange first -> clockwise, blue first
    # -> counter-clockwise. v5 decides this from the inner wall areas instead, but
    # that only works from the parking position, which the open challenge doesn't
    # start in. Until a line has been seen it stays None and the corner turn falls
    # back to comparing the two sides.
    driving_direction = None
    final_run_initiated = False
    final_run_start_time = None
    final_run_start_pos = None

    cpr = motor.encoder.counts_per_rev if (motor.encoder is not None) else (48 * 4.4 * 38 / 13)
    wheel_diameter_mm = motor.encoder.wheel_diameter_mm if (motor.encoder is not None) else 62.4
    circ_cm = (math.pi * wheel_diameter_mm) / 10.0

    perf = PerfMonitor()
    frame_debug_throttle = Throttle(1.0)

    try:
        run_start_time = time.monotonic()
        motor.start_rpm_control(TARGET_RPM, direction="forward")
        camera_stalled = False

        while True:
            angle = 0
            debug = []

            # Blocking wait -- no busy-spin, same as the obstacle loop.
            frame, frame_counter, capture_ts, fresh = camera_thread.get_next_frame(past_frame_counter)
            if frame is None or not fresh:
                # Stale frame -- see CameraThread.get_next_frame(). Cut power rather
                # than steer on pixels we already used.
                if not camera_stalled:
                    camera_stalled = True
                    log.critical("CAMERA STALL: no new frame for >%.0f ms after f=%d "
                                 "-- stopping motor.",
                                 CAMERA_STALE_TIMEOUT_S * 1000.0, past_frame_counter)
                    motor.stop_rpm_control()
                    motor.brake()
                continue
            if camera_stalled:
                camera_stalled = False
                log.warning("CAMERA STALL over -- restarting motor control.")
                motor.start_rpm_control(TARGET_RPM, direction="forward")
            skipped = max(0, frame_counter - past_frame_counter - 1)
            past_frame_counter = frame_counter
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

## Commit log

2026-04-05 Coded encoder, made changes to obstacel challenge to target a specifc angle from block rather than a specific line.
2026-04-05 fixed drawing of target line/angle
    [main_v3.py]
2026-06-29 refactor(sensors): implement shared I2C bus lock and add BNO086 IMU driver
2026-06-29 feat(sensors): switch to dual VL53L4CD distance sensors and remove VL53L1X
2026-06-29 feat(motors): add closed-loop wheel RPM control and servo centering utility
2026-07-04 fix: correct encoder polarity sign and add diagnostic tools for motor and sensor validation
    [main_v4.py, motor.py]
2026-07-04 feat: add diagnostic scripts for encoder stalling and VL53L8CX sensor testing, plus documentation updates and utility scripts
2026-07-04 docs: update mobility and mechanical design targets and powertrain calculations
2026-07-30 fix(motors): fix stall ramp bug, add feed-forward duty and smooth rpm logging
    [motor.py]
2026-07-30 perf(camera): capture 640x360 directly from ISP to save CPU and memory bandwidth
2026-07-30 feat(sensors): add gyro invert config option and BNO086 calibration script
    [bno055.py, bno086.py, calibrate_bno.py]
2026-07-30 refactor(main): sync challenge main code with async video writer and thread cleanup
2026-08-01 refactor(sensors): update distance sensor driver for multi-sensor bringup and optional channels
2026-08-01 feat(teleop): expand steer max angle to 60 deg and use unlimited servo angle
2026-08-04 refactor: organize codebase into tools/ and legacy/ directories and add power profiler
2026-08-08 refactor: move vision, threads, and logging into shared top-level packages
2026-08-08 updated diagrams and readme for mobility power and systems
2026-08-08 Adding 3D Printed Parts` Models And Photos
    [BearingToWheelShaft.stl, BottomChasis.stl, CameraMount.stl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]
2026-08-08 Updating schemes with circuit diagram, 3d part pics and final chassis
2026-08-08 Added PCB Models And Robot Building Images
    [HAT+.kicad_pcb, HAT+.kicad_sch, HAT_Plus_sch.kicad_sch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]
2026-08-09 Adding diagrams for systems thinking, mobility and power n sense
2026-08-09 feat: add speed sweep telemetry reports and gyro-based trajectory experiment scripts
2026-08-11 Minor changes to README
    [All_3D_Parts.3mf]
2026-08-14 refactor: upgrade BNO086 to absolute rotation vector, add dynamic calibration control, and tune obstacle avoidance logic
    [bno086.py, calibrate_bno.py, camera.py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]
2026-08-14 feat: switch BNO086 sensor to game rotation vector to eliminate magnetometer dependency
2026-08-16 Zooming in torque handwritten calculations diagram
2026-08-18 feat: add power management utilities and improve obstacle challenge navigation logic with robust direction detection and enhanced block tracking
2026-08-20 feat: introduce Watchdog and SystemHealth threads to monitor control loop responsiveness and thermal throttling.
2026-08-22 refactor: upgrade open challenge main loop to rpm-based motion control and replace heartbeat-based watchdog logic with encoder-tracked final stopping distance
    [config.py, hw_threads.py, main.py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]
2026-08-22 feat: implement camera stall detection to cut motor power when frames are delayed beyond the defined timeout threshold.
    [hw_threads.py, main.py, maneuvers.py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]
